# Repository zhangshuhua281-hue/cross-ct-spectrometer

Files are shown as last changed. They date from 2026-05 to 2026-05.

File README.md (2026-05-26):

# Cross C-T Spectrometer Prototype

交叉式 C-T 光谱仪原型设计。这个仓库整理了一个低成本光谱仪原型的光学设计、结构件、PCB、嵌入式固件、BOM 和实测数据处理结果，目标是方便复现、验证和继续改进。

本项目是实验原型，不是成熟仪器。当前资料适合学习、二次开发和原型复现；若用于定量测量，需要继续完成波长标定、白参考/暗参考流程、重复性验证和误差评估。

## What is included

- `hardware/optics/zemax`: Zemax 光学设计文件。
- `hardware/pcb`: TCD1304 驱动板、STM32G431 图像数据处理板的原理图和 PCB 工程压缩包。
- `hardware/mechanical/step`: 光谱仪外壳、镜架、隔离板、测试模块等 STEP 结构件。
- `firmware/stm32g431-image-control`: STM32G431 数据处理与显示链路固件，Keil MDK 工程。
- `firmware/esp32s3-monitor`: ESP32-S3 触摸屏监视器 Arduino 工程。
- `firmware/stm32f103-tcd1304-recovered`: STM32F103/TCD1304 采集固件的恢复版源码和串口协议说明。
- `data`: V1.0/V2.0/V3.0 原始采集数据、405 nm/780 nm 标定数据、处理后的 CSV/图像和分析脚本。
- `bom`: 镜片材料采购清单。
- `docs/project-report/project-report.pdf`: 项目报告 PDF。

## Repository layout

```text
.
├── bom/
├── data/
│   ├── raw/
│   ├── calibration/
│   ├── processed/
│   ├── validation/
│   └── legacy/
├── docs/
├── firmware/
├── hardware/
├── requirements-analysis.txt
└── README.md
```

## Quick start

1. 查看总体方案：打开 `docs/project-report/project-report.pdf`。
2. 查看硬件：先看 `hardware/pcb/schematics` 中的原理图，再看 `hardware/mechanical/step` 中的结构件。
3. 查看固件：STM32G431 工程入口是 `firmware/stm32g431-image-control/MDK-ARM/image-control.uvprojx`，ESP32-S3 工程入口是 `firmware/esp32s3-monitor/11_stm32_monitor.ino`。
4. 查看数据：优先看 `data/processed/v3.0/README.md`、`data/processed/v3.0/reports/processing_report.md` 和 `data/processed/v3.0/final_comparison`。
5. 重新跑 Python 数据处理脚本时，安装依赖：

```bash
pip install -r requirements-analysis.txt
```

## Default embedded chain

- 采集端：STM32F103/TCD1304 通过 `USART2` (`PA2/PA3`, `921600 8N1`) 向 STM32G431 提供 3648 点 12 位原始帧。
- 处理端：STM32G431 完成暗电平估计、中值滤波、Savitzky-Golay 平滑、归一化和下采样。
- 显示端：STM32G431 通过 `USART3` (`PB10/PB11`, `115200 8N1`) 向 ESP32-S3 输出文本包。
- 握手线：G431 `PA5(DATA_RDY)` 提示有待发送包，ESP32 `GPIO21(WAKE)` 拉高后 G431 才发送该包。

## Firmware build notes

- `firmware/esp32s3-monitor` 现在已经包含本地 `bsp_cst816.h/.cpp`，克隆仓库后不再缺少触摸驱动头文件。
- ESP32-S3 工程仍依赖 Arduino 环境中的 `lvgl` 与 `Arduino_GFX_Library`。
- `hardware/pcb/eda-archives` 保存当前公开版本的 PCB 工程压缩包，压缩包内部文件名可能与仓库文件名不同。

## Current status

- 已整理光学、结构、PCB、固件和测量数据。
- 已包含 TCD1304 采集链路、STM32G431 处理链路和 ESP32-S3 显示链路。
- V3.0 数据包含 12 组色卡、每组 5 次重复采集，以及 405 nm/780 nm 波长锚点数据。
- 当前仍需要继续完善定量标定、上位机源码、自动化构建和硬件复现文档。

## License

除文件内另有声明外，本仓库原创代码、文档、硬件设计资料和整理后的数据以 MIT License 发布。第三方文件保留其原始许可证声明，尤其是 STM32 HAL/CMSIS 相关文件。详见 `LICENSE` 和 `NOTICE.md`。

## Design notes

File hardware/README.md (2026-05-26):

# Hardware

硬件资料按光学、PCB 和结构件分开整理。

- `optics/zemax`: Zemax 光学设计文件。
- `pcb/schematics`: 两块电路板的 PDF 原理图。
- `pcb/eda-archives/G431图像数据处理板.zip`: STM32G431 图像数据处理板工程压缩包。
- `pcb/eda-archives/TCD1304驱动板.zip`: TCD1304 驱动板工程压缩包。
- `mechanical/step`: 3D 打印和结构装配用 STEP 文件。

当前 `pcb/eda-archives` 目录中的压缩包外层文件名已经按板卡用途整理；使用时建议与 `pcb/schematics` 中同名原理图 PDF 对照确认。

这些文件对应原型设计阶段资料，开板或加工前建议重新检查尺寸、公差、接口、连接器朝向和器件封装。

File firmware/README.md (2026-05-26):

# Firmware

## STM32G431 image-control

路径：`stm32g431-image-control`

用途：从 STM32F103/TCD1304 采集板读取 3648 点 12 位数据，完成暗电平估计、中值滤波、Savitzky-Golay 平滑、归一化和下采样，并通过串口输出给 ESP32-S3 显示端。

默认链路：

- STM32F103/TCD1304 -> STM32G431 `USART2` (`PA2/PA3`, `921600 8N1`)
- STM32G431 -> ESP32-S3 `USART3` (`PB10/PB11`, `115200 8N1`)
- 握手线：G431 `PA5(DATA_RDY)` -> ESP32 `GPIO18`，ESP32 `GPIO21(WAKE)` -> G431 `PA0`

工程入口：

- Keil MDK: `stm32g431-image-control/MDK-ARM/image-control.uvprojx`
- 应用逻辑：`stm32g431-image-control/App`
- 串口/板级驱动：`stm32g431-image-control/BSP`

## ESP32-S3 monitor

路径：`esp32s3-monitor`

用途：触摸屏监视器，接收 STM32G431 串口输出并显示曲线、分组统计和链路状态。

工程入口：

- Arduino sketch: `esp32s3-monitor/11_stm32_monitor.ino`

构建说明：

- 目录内已包含本地触摸驱动 `bsp_cst816.h/.cpp`，不再依赖仓库外的同名头文件。
- 仍需在 Arduino/PlatformIO 环境中安装 `lvgl` 和 `Arduino_GFX_Library`。

## STM32F103 TCD1304 recovered firmware

路径：`stm32f103-tcd1304-recovered`

用途：记录从实物 Flash 反汇编整理出来的 TCD1304 采集固件逻辑、串口命令和积分时间表。

注意：这是恢复版源码，适合理解和移植，不保证直接编译得到与实物导出固件逐字节一致的 HEX。

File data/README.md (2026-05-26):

# Measurement Data

测量数据按原始数据、标定数据、处理结果和旧版分析结果分开。

## Raw data

- `raw/v1.0-cards`: V1.0 色卡与镜片参考采集数据。
- `raw/v2.0-cards`: V2.0 色卡采集数据。
- `raw/v3.0-cards`: V3.0 色卡采集数据，共 12 组，每组 5 次重复。

原始 TXT 通常包含 `Pixel, ADC, VoltageV` 三列。数据处理时默认跳过前 20 行瞬态/平台点，并使用前 16 点估计暗电平。

## Calibration data

- `calibration/405nm`: 405 nm 光源锚点数据。
- `calibration/780nm`: 780 nm 光源锚点数据。

## Processed data

- `processed/v1.0`: V1.0 数据处理脚本、CSV、报告和图像。
- `processed/v3.0`: V3.0 数据处理脚本、CSV、报告、最终对比和 405/780 nm 线性标定结果。

优先查看：

- `processed/v3.0/reports/processing_report.md`
- `processed/v3.0/final_comparison`
- `processed/v3.0/wavelength_calibration_405_780`

## Legacy and validation

- `legacy/origin-smooth-selected-skip20`: 早期平滑与差异分析结果。
- `validation/tcd1304-validity`: TCD1304 有效性和组间相关性分析结果。

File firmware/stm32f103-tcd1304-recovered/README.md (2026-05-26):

# STM32F103C8T6 采集固件恢复源码说明

这个目录是根据当前实物单片机 Flash 导出的 `tcd1304_mcu_flash_64k.bin/.hex` 反汇编后整理的源码包。

它不是原作者的原始工程源码。HEX/BIN 里没有变量名、注释、C 文件结构和 Keil 工程分组信息，所以这里整理的是“等价逻辑恢复版”，用于理解、继续移植和后续修改。

## 文件

- `src/tcd1304_firmware_recovered.c`
  - 采集固件主逻辑恢复版。
  - 包含串口命令处理、积分时间表、12 位/8 位数据发送、摘要帧发送、DMA 完成中断逻辑。
- `docs/protocol.md`
  - 上位机与单片机串口协议。
- `docs/recovery_notes.md`
  - 恢复依据、已确认硬件、未完全还原部分。

## 已确认功能

- 串口：USART1，`921600 8N1`
- 采集命令：
  - `0xA1`：发送 3648 点 12 位数据，低字节在前，共 7296 字节。
  - `0xA2`：发送 3648 点 8 位数据，共 3648 字节。
  - `0xA3`：发送摘要帧，帧头 `0xFE`，共 12 字节。
- 积分时间命令：
  - `0xB1` 到 `0xD8`
  - 对应 `10 us` 到 `3 s`

## 重要边界

当前目录里的源码适合继续开发和移植，但不能保证直接编译后得到和实物导出固件逐字节相同的 HEX。

如果要在源码层继续改单片机逻辑，建议以 `src/tcd1304_firmware_recovered.c` 为依据，把 `board_*` 底层函数移植到 Keil 标准外设库工程中，然后用示波器确认 TCD1304 的 MCLK、SH、ICG 等时序。

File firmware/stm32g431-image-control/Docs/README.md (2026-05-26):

# image-control

STM32G431RBTx HAL base project for Keil5.

## Directory layout

- `App`: application logic, processing pipeline, group statistics
- `BSP`: board-level drivers and pin abstraction
- `Core`: startup, interrupt handlers, clock config, HAL MSP
- `Drivers`: local CMSIS and HAL drivers copied from STM32CubeG4
- `MDK-ARM`: Keil5 project files
- `Docs`: project notes

## Current baseline

- Device target: `STM32G431RBTx`
- Framework: `STM32CubeG4 HAL`
- Clock: HSI -> PLL -> 170 MHz
- Input UART: `USART2`, `PA2(TX)` / `PA3(RX)` linked to the STM32F103 TCD1304 capture board
- Display link UART: `USART3`, `PB10(TX)` / `PB11(RX)` to ESP32-S3 upper display
- `PA2` is reserved for `USART2_TX` in the default acquisition chain and must not be reused as a debug GPIO
- Handshake GPIO:
  - `PA5`: `DATA_RDY` output to ESP32 `GPIO18`
  - `PA0`: `WAKE` input from ESP32 `GPIO21`
- Processing scope for current firmware:
  - dark level estimation from the first 16 ADC points using median
  - skip the first 20 points
  - `Intensity = dark_adc - ADC`
  - 9-point median filter
  - 151-point 3rd-order Savitzky-Golay smoothing
  - clamp smoothed output to `>= 0`
  - max normalization on the smoothed curve
  - lightweight per-group accumulation and QC summary
- Not included yet:
  - white-reference normalization
  - area normalization
  - wavelength calibration
  - PC-side plots and reports
  - full-resolution multi-replicate history retention

## Embedded mapping to the PC workflow

- The G431 firmware keeps the main per-frame processing chain from `scripts/process_v3_tcd1304.py`.
- To stay within MCU RAM limits, it does not keep every full-resolution curve for every group.
- The firmware processes one frame at a time, then keeps only:
  - frame summary values
  - a downsampled normalized curve for current group QC accumulation
  - lightweight group-level statistics

## Serial protocol assumptions

- Input source on `USART2` is the recovered STM32F103 capture firmware.
- G431 requests one frame by sending command `0xA1`.
- F103 replies with one full 12-bit frame:
  - `3648` pixels
  - `2` bytes per pixel
  - little-endian (`low byte` then `high byte`)
  - total payload `7296` bytes
- Pixel axis used by the G431 pipeline:
  - first pixel index is treated as `0`
  - first `20` pixels are skipped by the processing chain
- Current group mapping in this firmware:
  - every pulled F103 frame is tagged as `group 1`
  - `replicate_id` is auto-incremented locally on G431 for QC accumulation
- ESP32 output content on `USART3`:
  - `PKT BEGIN SEQ=<n>`
  - `FRAME ...`
  - `GROUP ...`
  - `CURVE_BEGIN ...`
  - repeated `CURVE <pixel> <q15>`
  - `CURVE_END`
  - `PKT END`
- Handshake behavior:
  - every completed frame is converted into one display packet
  - `DATA_RDY` stays high while a packet is pending
  - if `WAKE` is low, the latest packet is held until ESP32 is ready
  - if `WAKE` is high, the packet is sent immediately
  - only one packet buffer is kept on the G431 side, so acquisition pauses until the pending packet is drained

## Next recommended changes

- Add DMA or interrupt-based UART receive on `USART2` if the F103 frame rate becomes too high for polling.
- Replace the temporary fixed `group 1` tag with a real group/replicate source if the upstream board can provide metadata.
- Keep wavelength calibration as a later stage after your new calibration data is ready.

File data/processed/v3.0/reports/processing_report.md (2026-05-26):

# V3.0 TCD1304 数据处理报告

## 数据理解

- 原始目录：`data/raw/v3.0-cards`
- 文件数：60；色卡组数：12；每组 5 次重复采集。
- 每个原始文件包含 `Pixel, ADC, VoltageV` 三列，实际像素点数为 3647。
- 前 20 行视为读出瞬态或起始平台，保留用于检查，但不纳入有效曲线。

## 处理流程

1. 按文件名 `A-B.txt` 解析 `A` 为色卡编号，`B` 为重复序号。
2. 取前 16 个高平台点的中位数作为 `dark_adc`。
3. 计算 `IntensityADC = dark_adc - ADC`。
4. 对有效曲线做 9 点中值滤波和 151 点三阶 Savitzky-Golay 平滑。
5. 每组 5 次测量求均值，输出组内重复性、组间相关矩阵和最终对比图。

## 主要结论

- 60 条样本可以按文件名稳定解析为 12 组，并完成组内重复性和组间相关矩阵汇总。
- 从组均值曲线和组间相关矩阵看，V3.0 数据的组间差异明显优于早期数据。
- 组内平均相关系数整体较高，说明重复采集的一致性较好。
- 第 12 组峰值位置明显偏后，需要结合采集条件确认它是有效样品差异还是采集异常。
- 当前波长标定只使用 405 nm 和 780 nm 两个锚点，属于线性初步标定，不能替代完整标定流程。

## 重点输出

- `data/04_quality_control/group_repeatability_stats.csv`
- `data/04_quality_control/between_group_correlation.csv`
- `data/02_group_means/all_group_means_smoothed_normalized_wide.csv`
- `final_comparison/V3.0_色卡最终对比图_平滑归一化.svg`
- `wavelength_calibration_405_780/405_780_线性波长标定公式.csv`

## QC 摘要

| 组别 | 重复数 | 组内平均相关 | 平均点位 CV | 平均峰值像素 |
|---:|---:|---:|---:|---:|
| 1 | 5 | 0.999896 | 0.002819 | 2343.8 |
| 2 | 5 | 0.999949 | 0.003127 | 2339.8 |
| 3 | 5 | 0.999917 | 0.001547 | 2339.4 |
| 4 | 5 | 0.999916 | 0.003826 | 2342.0 |
| 5 | 5 | 0.999877 | 0.002402 | 2340.2 |
| 6 | 5 | 0.999923 | 0.004357 | 2340.0 |
| 7 | 5 | 0.999940 | 0.001955 | 2337.0 |
| 8 | 5 | 0.999806 | 0.002343 | 2076.8 |
| 9 | 5 | 0.999936 | 0.003482 | 2338.6 |
| 10 | 5 | 0.999941 | 0.001884 | 2340.0 |
| 11 | 5 | 0.999955 | 0.003770 | 2340.4 |
| 12 | 5 | 0.999946 | 0.001186 | 3450.4 |

未发现完全重复文件。

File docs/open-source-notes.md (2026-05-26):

# Open Source Notes

整理时保留了能帮助复现和验证的资料，排除了更适合发布到 GitHub Releases 或不适合公开再分发的文件。

## Kept

- 光学设计文件、PCB 原理图和 PCB 工程压缩包。
- 结构 STEP 文件。
- STM32G431、ESP32-S3 和 STM32F103 恢复版固件资料。
- V1.0/V2.0/V3.0 原始采集数据。
- V1.0/V3.0 处理后的 CSV、SVG、PNG 和脚本。
- 项目报告 PDF。

## Excluded

- 编译输出和本地工程临时文件。
- 预编译 Windows 上位机 EXE。
- MATLAB `.fig` 二进制图。
- 参赛视频、PPT、DOCX。
- 参考文献 PDF。

## Before publishing

发布到 GitHub 前建议人工检查一次 `docs/project-report/project-report.pdf`，确认其中没有不想公开的姓名、学校、联系方式、比赛账号或未授权图片。

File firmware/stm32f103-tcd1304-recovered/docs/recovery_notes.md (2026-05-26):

# 固件恢复说明

## 来源

恢复依据是当前实物 STM32F103C8T6 读出的完整 Flash：

- `tcd1304_mcu_flash_64k.bin`
- `tcd1304_mcu_flash_64k.hex`

反汇编与分析文件包括中断向量、函数反汇编和恢复版伪代码。当前开源仓库只保留整理后的恢复版源码和说明。

## 与旧工程的关系

旧 Keil 工程的 `OBJ/USART.hex` 和当前实物单片机里的固件不同。

从旧工程源码看，它更像是通过 USART2 向另一个采集模块请求数据的程序；而实物固件本身使用 ADC1、DMA1 Channel1、TIM2/TIM3/TIM4/TIM1 和 USART1，直接完成 TCD1304 采集和数据返回。

所以本目录没有直接覆盖旧工程，而是单独整理恢复版源码，避免把两个不同固件混在一起。

## 已确认硬件/外设

| 项目 | 恢复结果 |
|---|---|
| MCU | STM32F103C8T6，Flash 64KB |
| 串口 | USART1，921600 8N1 |
| ADC | ADC1 |
| DMA | DMA1 Channel1 |
| 定时器 | TIM1、TIM2、TIM3、TIM4 均有使用 |
| 中断 | USART1、DMA1 Channel1、TIM2 |
| ADC DMA 源地址 | `0x4001244C`，即 ADC1 数据寄存器 |
| DMA 目标缓冲 | RAM `0x20000064` |
| 发送工作缓冲 | RAM `0x20001D40` |
| 原始 DMA 点数 | `0xE6E`，即 3694 点 |
| 实际发送像素 | 3648 点 |
| 发送起始偏移 | 跳过原始缓冲前 32 点 |

## 未完全还原的部分

这些内容在 HEX 里可以看到寄存器行为，但没有原始语义名，需要用示波器或实物电路继续确认：

- PA8、PA0、PB0、PB9 分别对应 TCD1304 的哪个具体时序脚。
- TIM1/TIM2/TIM3/TIM4 之间的触发关系。
- `timing_a`、`timing_b`、`timing_c` 三个参数在原始源码中的变量名。
- 长积分时间下，传感器暗电流、饱和、时钟稳定性对采集结果的影响。

## 后续改源码的建议

如果要继续修改积分时间，优先改 `src/tcd1304_firmware_recovered.c` 里的 `kIntegrationPresets` 表。

如果要把恢复版变成可重新编译的 Keil 工程，建议步骤是：

1. 复制旧 Keil 工程为新目录，不要覆盖原目录。
2. 把 `src/tcd1304_firmware_recovered.c` 拆成 `main.c`、`tcd1304.c`、`tcd1304.h`。
3. 在工程中加入 `stm32f10x_adc.c`、`stm32f10x_dma.c`、`stm32f10x_tim.c`。
4. 用 STM32 标准外设库实现源码中的 `board_*` 底层函数。
5. 编译后先在示波器上确认 TCD1304 时序，再接上位机采集。

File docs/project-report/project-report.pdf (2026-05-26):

附件 6

# 创意组

# 创意策划书

## 竞赛题目： 交叉式 C-T 光谱仪原型设计

竞赛队名： | 分光捉影

指导教师推荐理由：（希望评委关注的亮点，言简意赅、切忌浮夸、否则会影响成绩、80

字内）

1、利用交叉 C-T 光路，光谱仪集成度高，可实现轻量化微型化

2、光谱仪动态范围广，采集数据稳定可靠

3、系统采用模块化设计，具备多领域应用拓展能力
4、
5、 | 织委员会制

### 二〇二六年四月

序号

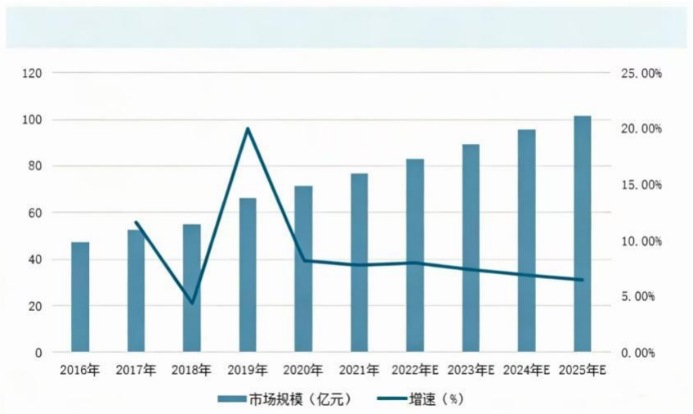
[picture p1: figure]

创

意

策

划

方

案

## 一、产品背景以及市场分析

通过对目前微型光谱仪和光纤光谱仪系统的分析可得。光谱信息能够反映被测 物体对不同波长光的吸收、反射或透射特性，因此可用于材料识别、颜色分析、环 境检测、物质成分判断等场景。
行业报告显示，中国光谱仪产量从 2019 年的 2.14 万台增长至 2023 年的 3.85 万台，同期需求量为 4.01 万台，显示出稳定的市场供需关系。且全球光谱仪市场 持续增长，市场规模从 2016 年的 47.2 亿元增长至 2024 年的 102.1 亿元。这些数据

表明，光谱仪市场，特别是中国市场和特定技术领域，拥有坚实增长基本盘。 二、国内外技术分析

目前，国内外光谱仪技术已经较为成熟，国外代表性产品具有检测精度高、稳 定性好、软件系统完善等特点，但价格普遍较高，在中低端市场存在明显价格壁垒。 国内光谱仪技术近年来发展较快，但微型光谱仪刚起步，集成度高但波长范围窄、 分辨率受限，往往难以获得理想的检测效果。
因此，设计一种精度高、价格低廉的微型光谱仪具有一定意义。本项目以此为 定位，采用交叉式 C-T 光路并配合自研采集系统，提升反射光谱采集的稳定性和颜

色差异分析能力。 三、技术方案论证

光谱仪是一种光学精密仪器，它的核心功能是将待测光信号按照不同波长进行 空间分离，并通过探测器采集不同波长处的光强信息，最终得到物体或样品的光谱 曲线，由狭缝、准直镜、色散元件、聚焦镜、成像系统等部分组成。本方案在此基 础之上给予创新，由三大模块构成：第一部分为前置照明与反射测量光路，第二部 分为光谱分光与成像系统，第三部分为信号采集、处理与显示系统。 设计过程先根据分辨率、狭缝宽度、光栅线数和 CCD 有效长度计算初始参数，

图 1.2016—2025 年中国光谱仪市场规模及预测情况

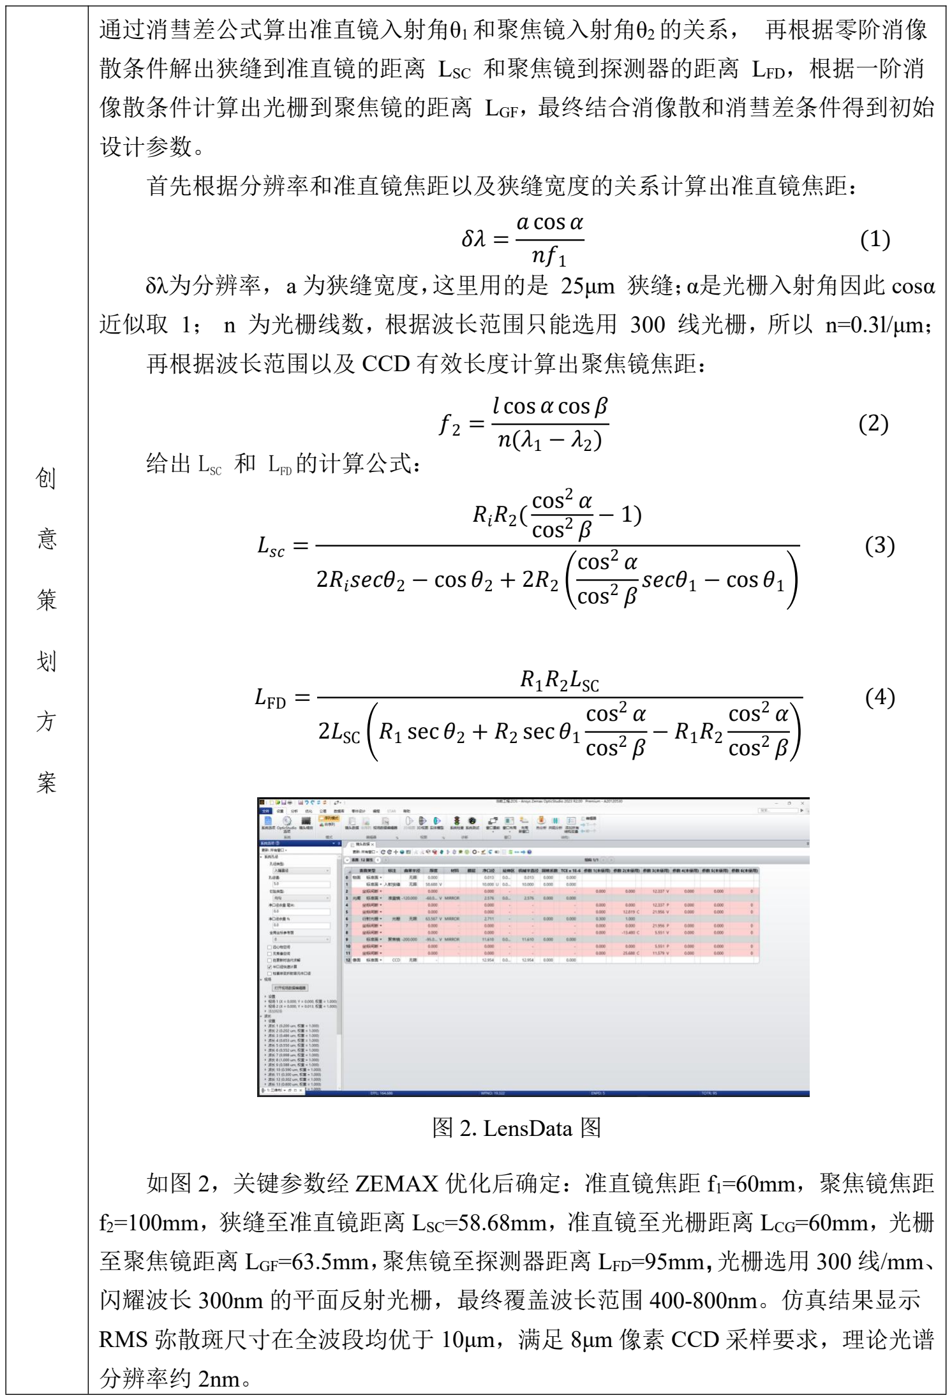
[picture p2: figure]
通过消彗差公式算出准直镜入射角θ1和聚焦镜入射角θ2的关系， 再根据零阶消像; 散条件解出狭缝到准直镜的距离 LSC 和聚焦镜到探测器的距离 LFD，根据一阶消; 像散条件计算出光栅到聚焦镜的距离 LGF，最终结合消像散和消彗差条件得到初始; 设计参数。; 首先根据分辨率和准直镜焦距以及狭缝宽度的关系计算出准直镜焦距：; δλ为分辨率，a 为狭缝宽度，这里用的是 25μm 狭缝；α是光栅入射角因此 cosα; 再根据波长范围以及 CCD 有效长度计算出聚焦镜焦距：; 给出 LSC 和 LFD的计算公式：; 如图 2，关键参数经 ZEMAX 优化后确定：准直镜焦距 f1=60mm，聚焦镜焦距; 至聚焦镜距离 LGF=63.5mm，聚焦镜至探测器距离 LFD=95mm，光栅选用 300 线/mm、; 闪耀波长 300nm 的平面反射光栅，最终覆盖波长范围 400-800nm。仿真结果显示; 分辨率约 2nm。;  cos  1;  cos  cos  (1 − 2); 2( cos; cos; 2s2 − cos 2 + 22; s1 − cos 1; 12SC 2SC 1 sec 2 + 2 sec 1; 图 2.LensData 图

近似取 1； n 为光栅线数，根据波长范围只能选用 300 线光栅，所以 n=0.3l/μm；

## f2=100mm，狭缝至准直镜距离 LSC=58.68mm，准直镜至光栅距离 LCG=60mm，光栅

RMS 弥散斑尺寸在全波段均优于 10μm，满足 8μm 像素 CCD 采样要求，理论光谱

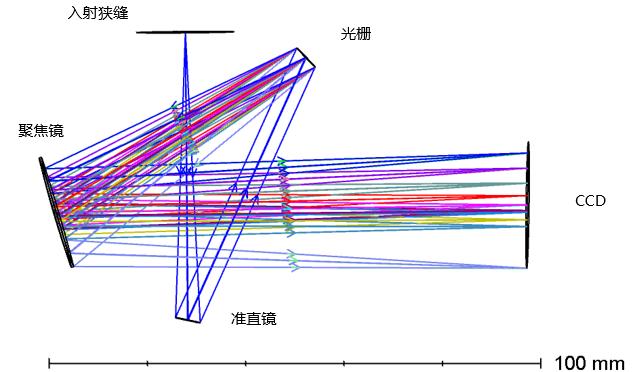
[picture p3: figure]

创

意

策

划

方

案

本方案采用交叉式 Czerny-Turner（C-T）结构，对比非交叉式 C-T 结构，空间 利用率更高，杂散光路径更短，整机尺寸可控制在 160×180×85mm 以内，满足 Shafer 彗差消除条件，同时引入零阶及一阶像散消除约束，通过 ZEMAX 光学仿真优化。

图 3 展示了优化后交叉式 C-T 结构光谱仪的光路设计结果，为进一步验证该结 构在全波段范围内的成像质量，下面结合图 4 所示的光路点列图，对不同波长下的

像点分布及弥散特性进行分析。

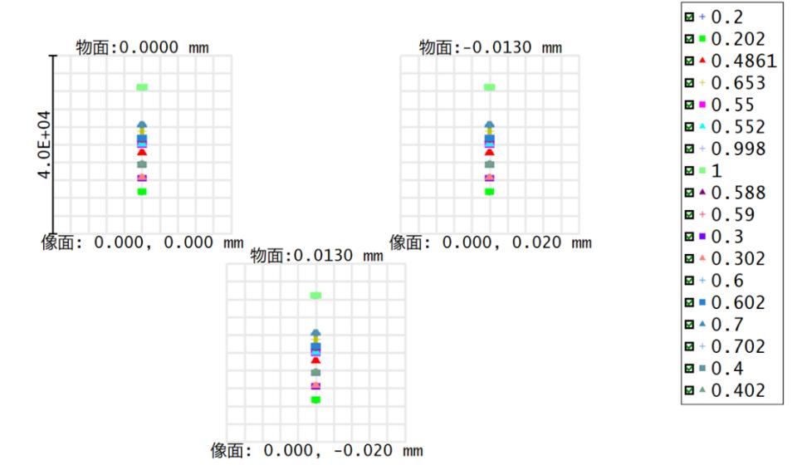
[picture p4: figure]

从图 5 可看出，优化后的结构在色散方向的像散显著降低，像点分布集中、弥

散范围较小；即使存在轻微像散，也应主要沿非色散方向分布，以减小对光谱分辨 率的影响。

图 3.光路结构示意图

图 4.光路点列图

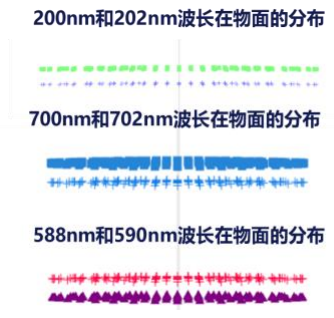
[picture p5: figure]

创

意

策

划

方

案

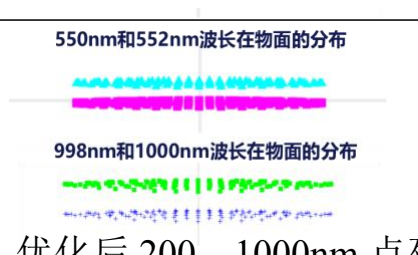
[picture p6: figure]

除光路设计与优化外，项目还自主完成了电子采集、参数配置和数据输出系统， 使样机具备可运行、可重复测试和可规范导出的工程能力。
项目围绕 TCD1304 线阵 CCD 自研驱动板，集成 3.3V 稳压、去耦滤波、8MHz 晶振、STM32F103C8T6 主控、CCD 接口和串口/下载接口。下位机输出 SH、ICG、 M 等关键时序，完成积分时间切换、采样数据打包和串口上传。相比通用开发板飞

线调试，自研板卡能够缩短信号链路，降低噪声耦合和接触不稳定问题，也便于后 续与光机外壳进行一体化安装。

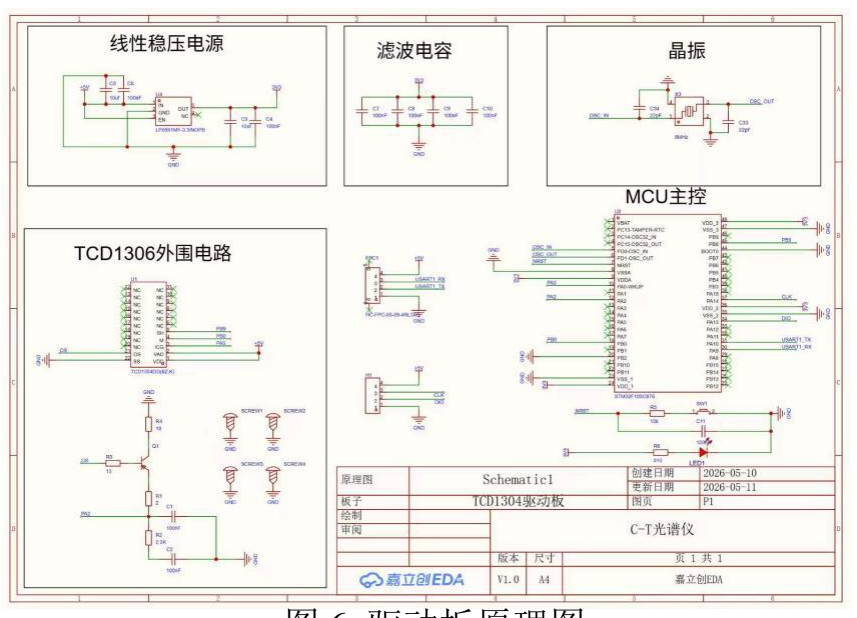
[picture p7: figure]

在原理图确定后，进一步完成了驱动板 PCB 布局布线与三维结构建模，如图 7 及图 8 所示。PCB 布局将主控、时钟、电源和 CCD 接口分区布置，缩短关键控制 线和模拟输出线。系统支持完整数据帧，积分时间可由 10μs 扩展至 3s，常规色卡 测试可在 1-200ms 范围内调节，从而兼顾弱信号可见性与强信号防饱和需求。

## 图 5.优化后 200—1000nm 点列图

图 6.驱动板原理图

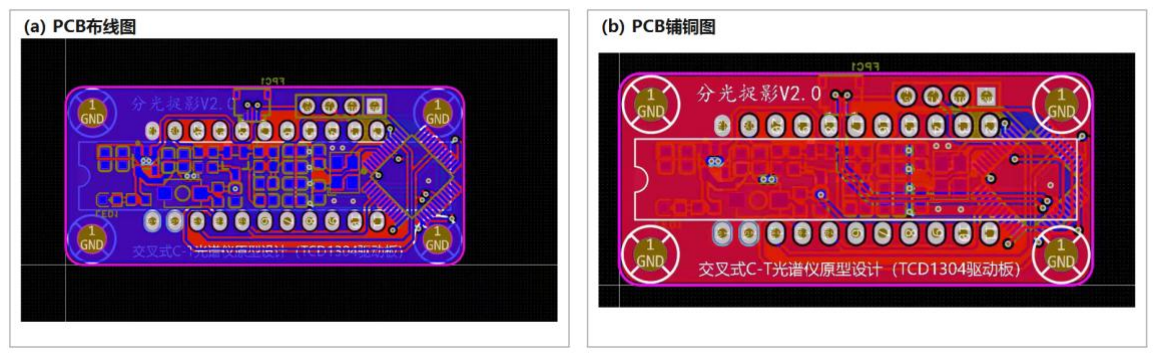
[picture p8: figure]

图 7.PCB 布线图及其铺铜图

创

意

策

划

方

案

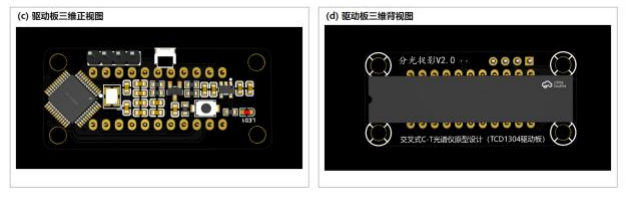
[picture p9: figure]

上位机采用 C# WinForms 开发，支持串口连接、实时曲线显示、手动/定时采 集、积分时间设置、单次导出和批量导出。导出数据统一包含 Pixel、ADC 和 VoltageV 三列，可直接进入 Python 或 MATLAB 处理流程，减少人工整理误差，并为暗电平

扣除、白纸校正、面积归一化和波长标定提供统一数据基础。 驱动板、STM32 固件与上位机共同构成完整采集链路：硬件提供稳定接口， 固件执行 CCD 时序和数据上传，软件完成显示、配置、导出和后续校正，为样机

实测、波长标定与颜色区分提供支撑。 四、技术路线设计及产品外观

整机工作流程：宽谱 LED 发光→准直透镜→半透半反分束镜（50:50）；透射

部分射向被测样品/参考白板，反射光返回后经分束镜二次反射；反射部分与样品 反射光在第二聚焦透镜处汇聚，共同耦合进入入射狭缝；光经狭缝进入 C-T 分光系 统完成色散和成像，线阵 CCD 采集光谱。

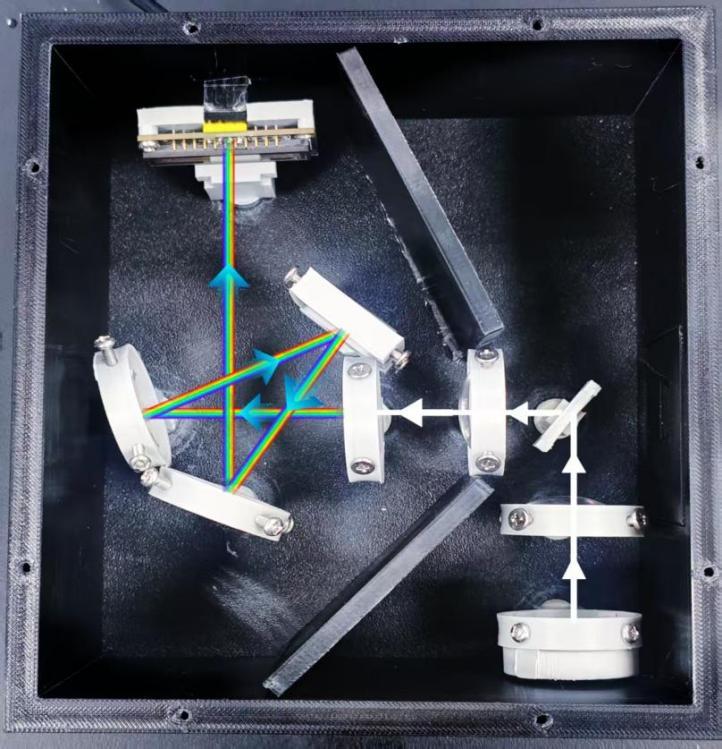
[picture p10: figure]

图 9.光谱仪实体图

图 8.驱动板三维图

创

意

策

划

方

案

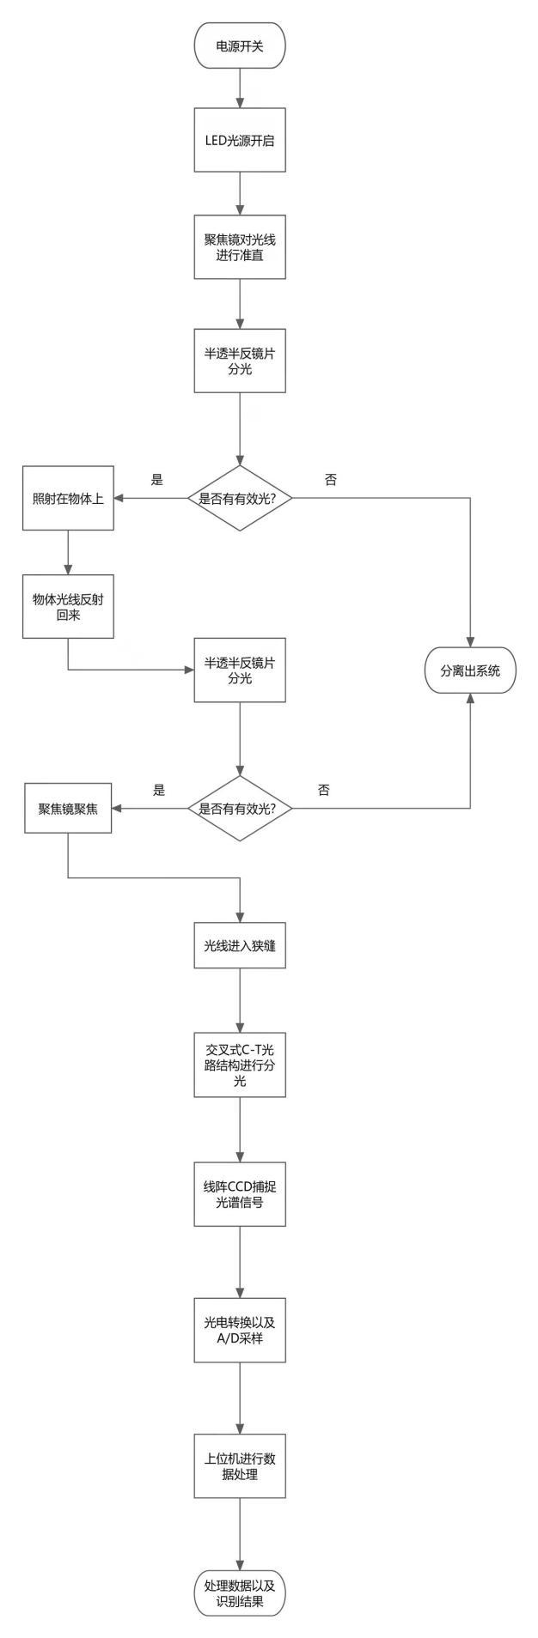
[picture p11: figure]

图 10.整机工作流程图

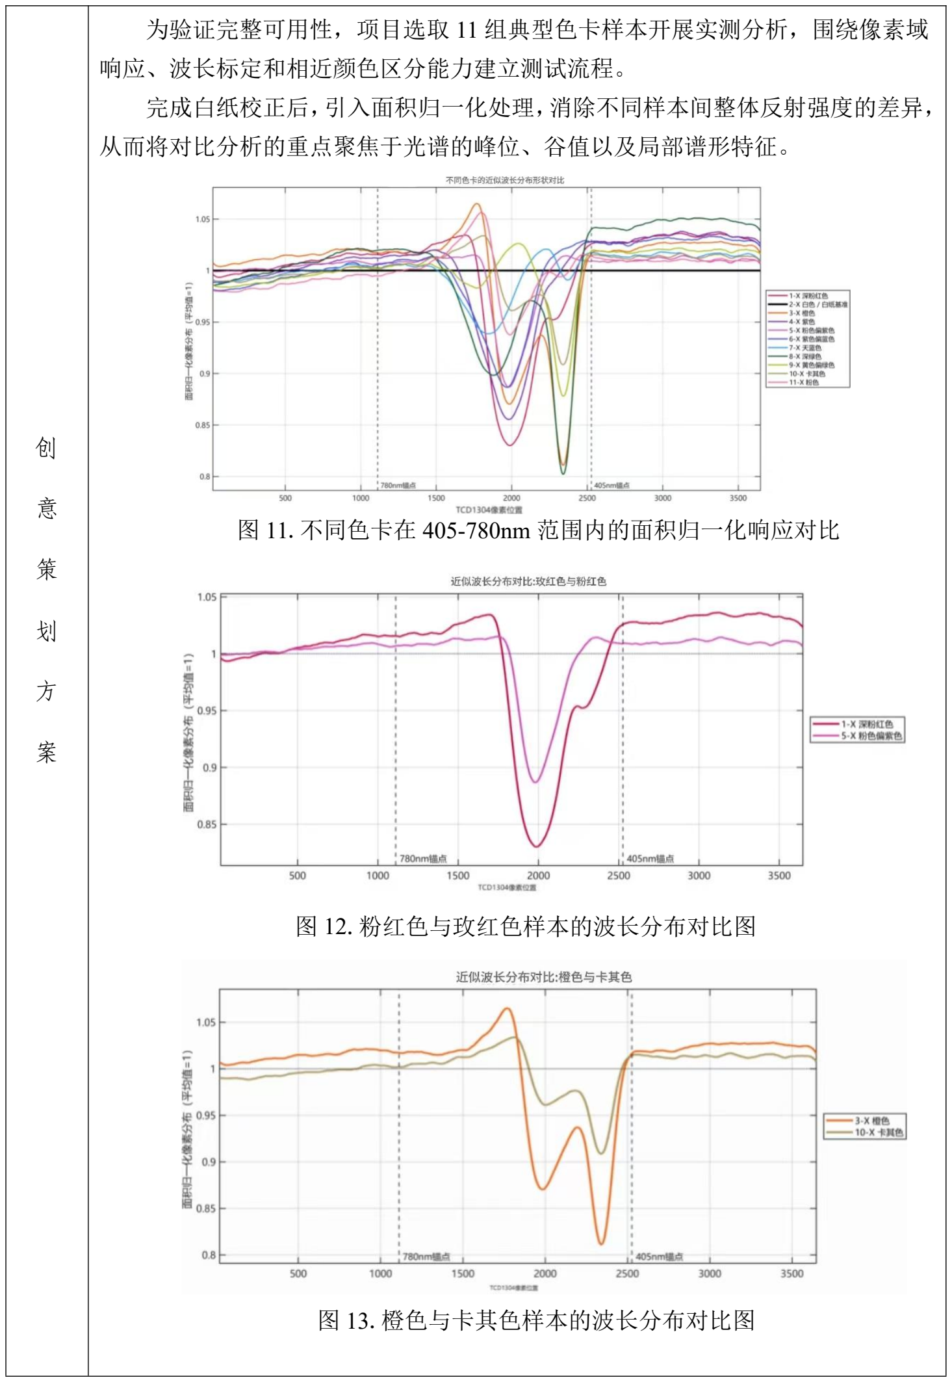
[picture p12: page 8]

创

意

策

划

方

案

为验证完整可用性，项目选取 11 组典型色卡样本开展实测分析，围绕像素域

响应、波长标定和相近颜色区分能力建立测试流程。
完成白纸校正后，引入面积归一化处理，消除不同样本间整体反射强度的差异， 从而将对比分析的重点聚焦于光谱的峰位、谷值以及局部谱形特征。

图 11.不同色卡在 405-780nm 范围内的面积归一化响应对比

图 12.粉红色与玫红色样本的波长分布对比图

图 13.橙色与卡其色样本的波长分布对比图

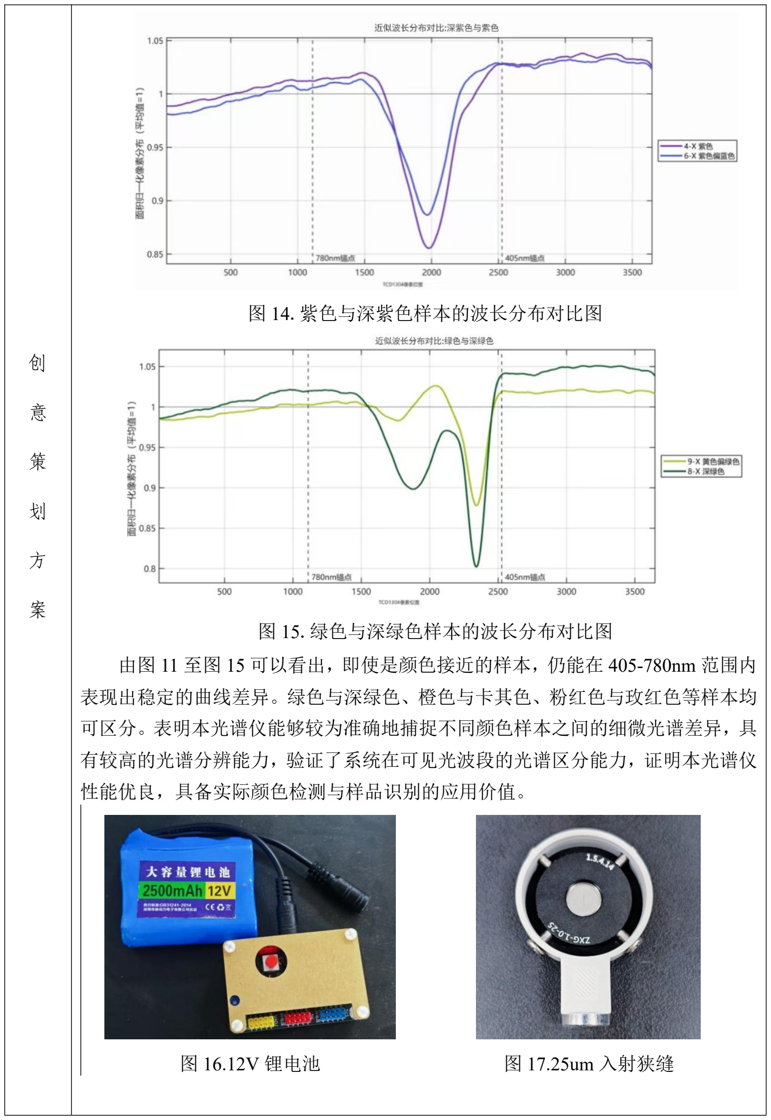
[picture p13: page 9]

创

意

策

划

方

案

由图 11 至图 15 可以看出，即使是颜色接近的样本，仍能在 405-780nm 范围内

表现出稳定的曲线差异。绿色与深绿色、橙色与卡其色、粉红色与玫红色等样本均 可区分。表明本光谱仪能够较为准确地捕捉不同颜色样本之间的细微光谱差异，具 有较高的光谱分辨能力，验证了系统在可见光波段的光谱区分能力，证明本光谱仪 性能优良，具备实际颜色检测与样品识别的应用价值。

图 16.12V 锂电池 | 图 17.25um 入射狭缝

图 14.紫色与深紫色样本的波长分布对比图

图 15.绿色与深绿色样本的波长分布对比图

图 18.300 线 300nm 闪耀波长 | 图 19.焦距 100mm 反射式聚焦镜

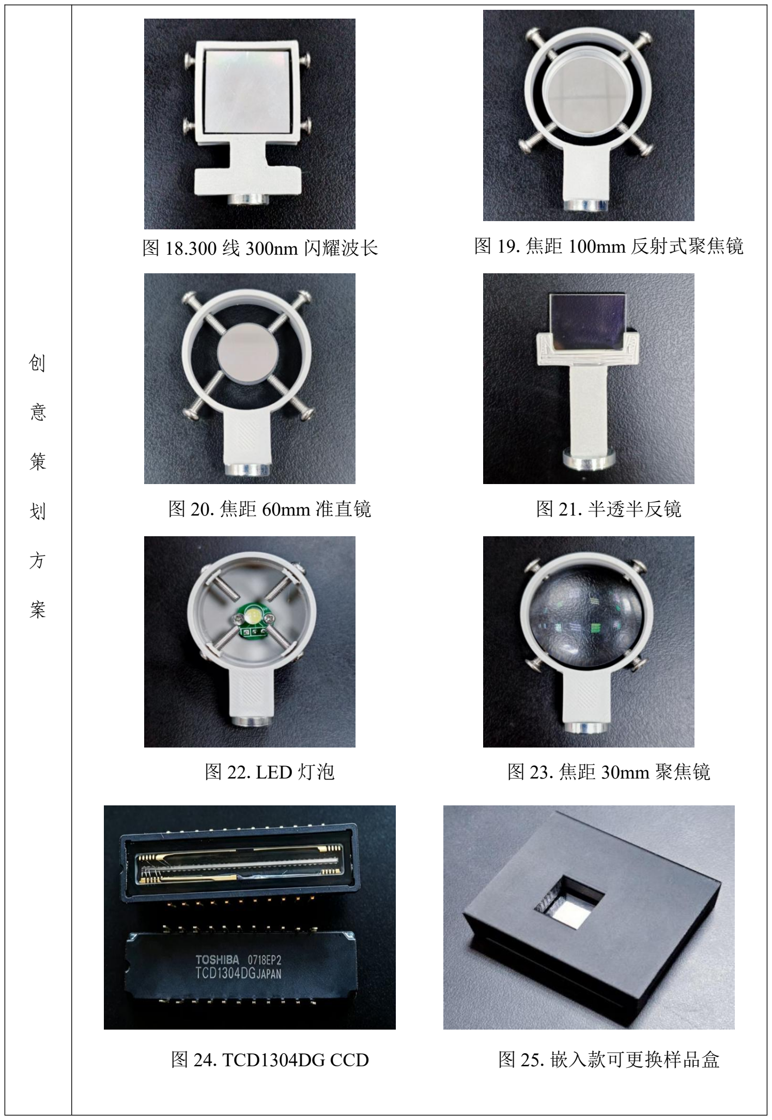
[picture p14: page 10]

创

意

策

划

方

案

图 20.焦距 60mm 准直镜 | 图 21.半透半反镜
图 22.LED 灯泡 | 图 23.焦距 30mm 聚焦镜
图 24.TCD1304DG CCD | 图 25.嵌入款可更换样品盒

创

意

策

划

方

案

## 入射狭缝：狭缝宽度 25±5um，长度 3mm,材料为 302Stainless Steel，直径

25.4mm。
衍射光栅：平面衍射光栅尺寸 25×25mm，厚度为 6mm，刻线为 300L/mm，闪

## 耀波长为 300nm，衍射波段为：200-850nm。

反射式聚焦镜：尺寸直径为 25mm，焦距为 100mm，边厚为 6.39mm，厚度为 6mm，镀膜为紫外铝膜，材料为精退火 H-K9L 光学玻璃。

准直镜：尺寸直径 17mm，焦距 60mm，曲率半径为 120mm，中心厚度为 3.7mm， 边缘厚度为 4.75mm，凹面镀膜为紫外增强铝膜。

## 半透半反镜：尺寸为 14×17×1.1mm，波长指标为 400-700nm，镀膜为 IAD 多

层介质硬膜。

聚焦镜×2：透射式聚焦镜，直径 30mm，焦距 30mm。

## TCD1304DG：东芝 TCD1304，像素大小为 8um×200um，像素共计 3684，波 长响应范围为 300nm—1000nm。

嵌入款可更换样品盒：外部结构尺寸为 50×60×17mm，内设小孔 15×15×7mm，

可更换光谱仪需要测试的样品。 五、创新性

本系统在结构设计、检测性能和应用拓展方面具有较强的创新性，主要体现在 以下三个方面。
系统具有显著的微型化与集成化优势。装置采用交叉式 Czerny-Turner 光路结 构，将光源、分光、探测及信号处理等核心光学元件高度集成于 PETG 外壳内部， 整机尺寸约为 160×180×85mm，在保证光谱检测功能完整性的同时，实现了设备

的小型化、轻量化与便携化。
团队自研 TCD1304 驱动板、STM32 采集固件和 C#上位机程序，实现 CCD 时

序驱动、积分时间调节、实时显示、批量采集和标准化导出。该链路使系统不仅能 够采集数据，而且能够稳定重复测试、规范保存数据并持续优化，增强了自主技术 含量和工程完整性。
系统具备高精度、快速响应的光谱检测能力。系统采用线阵 CCD 探测器进行

全波段同步采集，兼顾检测效率与信号质量。与此同时，系统支持自动曝光控制， 可依据样品反射率强弱自动优化积分时间，从而提升动态范围和测量稳定性。 系统具有良好的适用性与应用扩展能力。一方面，本系统可对不同颜色、不同 材质样品的反射光谱进行采集与分析。另一方面，系统具备较强的模块化扩展潜力： 可将检测范围进一步拓展至近紫外或近红外波段，从而应用于荧光检测、植被分析、 食品品质检测等更多领域。

创

意

策

划

方

案

| 综上，本系统以微型化设计、高精度检测及模块化拓展为核心创新点，具备显 著的自主化水平与实际应用前景。 六、产品成本及市场估值
产品零件 | 型号/规格 | 数量 | 单价
CCD | TCD1304DG | 1 | 100
入射狭缝 | 缝宽 25um | 1 | 145
衍射光栅 | 25×25×6mm,刻线 300,闪耀波长 300nm | 1 | 320
镀银凹面准直镜 | 焦距 60mm | 1 | 95
紫外铝凹面聚焦镜 | 焦距 100mm | 1 | 240
半透半反镜 | 14×17×1.1mm | 1 | 13
聚焦镜 | 直径 30mm | 2 | 60
反射镜 | 25×25mm | 1 | 2
LED 灯 | 5V | 1 | 5
锂电池 | 3S，12V | 1 | 12
合计 | —— | —— | 992
1.市场现状

光谱检测广泛应用于食品安全、工业在线质检、医疗辅助诊断等多个领域。随 着智能制造、食品监管和科学仪器国产化需求增长，国内光谱仪市场呈现出稳定上 升态势。根据市场研究数据，全球光谱仪市场规模 2024 年已超过 100 亿元，预计 到 2028 年将突破 280 亿元，年均增速约 7%。具备高度集成、低成本特点的微型光

谱仪在国内市场具有巨大的发展潜力。
2.产品种类和价格

企业版：适用于纺织、印刷、涂料等工业质检用户及高校科研实验室，针对客 户需求进行定制化开发，提供更高精度和专属技术支持服务，定价 20000-30000 元。

民用版：适用于个体用户、中学创新实验室，满足用户对便携式光谱检测及教

## 学演示的需求，定价 12000-15000 元。 七、团队介绍

团队具备光学设计、机械建模、嵌入式开发和市场分析能力能够完成从方案设 计到样机搭建、测试和推广的闭环。
团队成员一：负责光学设计、ZEMAX 仿真、SolidWorks 结构建模、STM32 驱 动、CCD 时序和 ADC 采集。完成了光谱仪光路系统的整体设计，在 ZEMAX 中建 立了交叉式 Czerny-Turner 光路模型，最终通过公差分析给出了镜片加工与装配的

公差范围，生成了可投入制作的光学设计文件。
团队成员二：负责机械结构搭建、样机装调、数据处理和颜色识别算法，并完

创

意

策

划

方

案

成外壳加工图纸与系统装配。绘制了外壳 3D 打印图纸，完成了样机装调，装配出

可工作的微型光谱仪。
团队成员三：主要负责项目财务管控与市场调研，推动微型光谱仪的商业化落 地。完成了核心元器件的供应链询价与 BOM 成本核算。搭建了销售预测模型，主

导了产品外形的概念设计、高精度渲染及宣发物料制作，构建了完整的产品商业体 系。
团队成员均具备一定的工程实践能力。成员分工明确，相互协作完成系统联调 与测试，保证各模块接口兼容、整机功能完整。 八、产品营销计划

1.定位市场：

本产品目标市场分三类：第一类为教研市场，高校光学/光电类实验室，需要 低成本、可操作性强的光谱仪，单台定价 12000-15000 元；第二类为工业质检市场， 纺织、印刷、涂料行业的颜色在线检测需求，单台定价 20000-30000 元；第三类为 消费电子融合方向，与手机端 APP 结合，面向个人用户，定价 10000 元以内。
2. 产品包装

产品设计风格在视觉上与品牌形象保持高度一致，呈现精密仪器的专业感与科 技感，使消费者能够快速识别产品系列归属。包装正面可开设透明亚克力观察窗， 令用户在开箱前即可感受到产品的工艺质感。包装背面以简洁的光路示意图配合文 字说明，直观呈现产品的功能优势与技术创新点

3.推广渠道策略

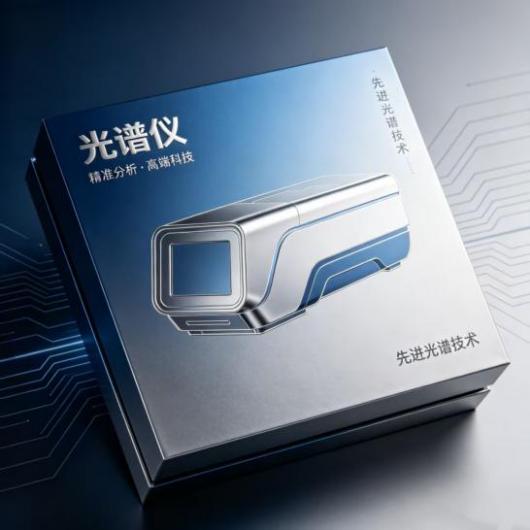
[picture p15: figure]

（1）学术渗透：在全国光学/仪器类学术会议设展位演示，借助学术口碑驱动 高校采购决策；

图 26.产品外包装图

创

意

策

划

方

案

（2）线上直营：建立官网+京东/淘宝旗舰店，提供在线技术文档、开源驱动 代码下载；
（3）高校代理：与各地区高校仪器设备代理商合作，利用其现有教育采购渠 道；
（4）KOL 合作：联系知乎光学/仪器类创作者进行产品评测视频投放，覆盖

高校学生与科研人员群体。
4. 商业模式设计

采用"硬件+软件+服务"三层盈利模式：硬件层：设备销售（基础款 19999 元， 专业款 29999 元）；软件层：数据分析订阅服务；服务层：为高校/企业提供专项

应用定制，项目制报价。
5. 带动就业前景

项目产业化后，预计在光学加工、精密机械、电子硬件、嵌入式软件、数据算 法、市场销售等方向形成多岗位就业需求。初期可直接带动 20—30 人就业；规模 化后直接就业岗位可扩展至 100 人以上，同时带动光学元件供应商、加工外协等上 下游就业约 50 人。产品面向高校开放开发接口，可吸引在校生基于本平台开展毕

业设计与创新创业项目，间接带动学生就业创业生态。

区赛 专家 评定 成绩 | 区赛评委得分： 区赛推荐排名：
组委 会意 见 | 组委会负责人（电子签名有效）： 年 月 日

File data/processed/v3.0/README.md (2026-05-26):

# V3.0 数据处理

处理入口：`scripts/process_v3_tcd1304.py`

主要结果优先看：

1. `reports/processing_report.md`
2. `data/02_group_means/all_group_means_smoothed_normalized_wide.csv`
3. `data/04_quality_control/group_repeatability_stats.csv`
4. `figures/group_means/group_mean_smoothed_normalized_overlay.svg`
5. `final_comparison/V3.0_色卡最终对比图_平滑归一化.svg`
6. `wavelength_calibration_405_780/405_780_线性波长标定公式.csv`

当前脚本默认从同级数据目录推导输入路径。若移动目录或只复制脚本，请同步调整 `INPUT_FOLDER` 和目录层级。

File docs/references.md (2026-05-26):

# References

本仓库不直接再分发参考文献 PDF，以避免版权问题。

已参考资料：

- 施仁杰，光纤光谱仪光学系统设计、建模与仿真。

后续建议补充 DOI、出版社链接或公开可访问链接。

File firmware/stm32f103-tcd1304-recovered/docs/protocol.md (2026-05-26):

# 串口协议与积分时间表

## 串口参数

- 外设：USART1
- 波特率：921600
- 数据位：8
- 校验：无
- 停止位：1

## 上位机命令

| 命令 | 功能 | 单片机返回 |
|---:|---|---|
| `0xA1` | 读取完整 12 位数据 | 3648 点，每点 2 字节，低字节在前，共 7296 字节 |
| `0xA2` | 读取完整 8 位数据 | 3648 点，每点 1 字节，共 3648 字节 |
| `0xA3` | 读取摘要数据 | 12 字节，首字节 `0xFE` |
| `0xB1`-`0xD8` | 设置积分时间 | 不返回数据，单片机重启采集时序 |

## `0xA3` 摘要帧

格式：

```text
FE
max_pos_high100 max_pos_low100
min_pos_high100 min_pos_low100
average_high100 average_low100
max_value_high100 max_value_low100
min_value_high100 min_value_low100
checksum
```

其中 `high100 = value / 100`，`low100 = value % 100`。

`checksum` 是前面 5 个数拆成 base-100 后 10 个字节的累加低 8 位。

## 积分时间命令

积分时间根据反汇编中的定时参数推算：

```text
integration_us = timing_a * timing_c / 72
```

| 命令 | 显示时间 | timing_b | timing_c | timing_a |
|---:|---:|---:|---:|---:|
| `0xB1` | 10 us | 15000 | 36 | 20 |
| `0xB2` | 20 us | 15000 | 36 | 40 |
| `0xB3` | 50 us | 15000 | 36 | 100 |
| `0xB4` | 60 us | 15000 | 36 | 120 |
| `0xB5` | 75 us | 15000 | 36 | 150 |
| `0xB6` | 100 us | 15000 | 36 | 200 |
| `0xB7` | 500 us | 15000 | 36 | 1000 |
| `0xB8` | 1.25 ms | 15000 | 36 | 2500 |
| `0xB9` | 2.5 ms | 15000 | 36 | 5000 |
| `0xBA` | 7.5 ms | 15000 | 36 | 15000 |
| `0xBB` | 10 ms | 20000 | 36 | 20000 |
| `0xBC` | 15 ms | 30000 | 36 | 30000 |
| `0xBD` | 20 ms | 40000 | 36 | 40000 |
| `0xBE` | 25 ms | 50000 | 36 | 50000 |
| `0xBF` | 30 ms | 60000 | 36 | 60000 |
| `0xC0` | 35 ms | 35000 | 72 | 35000 |
| `0xC1` | 40 ms | 40000 | 72 | 40000 |
| `0xC2` | 45 ms | 45000 | 72 | 45000 |
| `0xC3` | 50 ms | 50000 | 72 | 50000 |
| `0xC4` | 55 ms | 55000 | 72 | 55000 |
| `0xC5` | 60 ms | 60000 | 72 | 60000 |
| `0xC6` | 65 ms | 65000 | 72 | 65000 |
| `0xC7` | 70 ms | 35000 | 144 | 35000 |
| `0xC8` | 75 ms | 37500 | 144 | 37500 |
| `0xC9` | 80 ms | 40000 | 144 | 40000 |
| `0xCA` | 85 ms | 42500 | 144 | 42500 |
| `0xCB` | 90 ms | 45000 | 144 | 45000 |
| `0xCC` | 94.4 ms | 47200 | 144 | 47200 |
| `0xCD` | 100 ms | 50000 | 144 | 50000 |
| `0xCE` | 200 ms | 50000 | 288 | 50000 |
| `0xCF` | 300 ms | 37500 | 576 | 37500 |
| `0xD0` | 400 ms | 25000 | 1152 | 25000 |
| `0xD1` | 500 ms | 31250 | 1152 | 31250 |
| `0xD2` | 600 ms | 37500 | 1152 | 37500 |
| `0xD3` | 700 ms | 43750 | 1152 | 43750 |
| `0xD4` | 800 ms | 50000 | 1152 | 50000 |
| `0xD5` | 900 ms | 56250 | 1152 | 56250 |
| `0xD6` | 1 s | 62500 | 1152 | 62500 |
| `0xD7` | 2 s | 62500 | 2304 | 62500 |
| `0xD8` | 3 s | 46875 | 4608 | 46875 |

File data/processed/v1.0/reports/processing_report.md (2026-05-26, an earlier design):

# V1.0 TCD1304 数据处理报告

## 数据理解

- 原始目录：`data/V1.0采集数据`
- 本次处理文件数：41；其中色卡文件 35 个，镜片/参考文件 6 个。
- 色卡编号：1, 2, 3, 4, 6, 7, 8。当前目录没有编号 5 的色卡文件。
- 每个文件包含 `Pixel, ADC, VoltageV` 三列；本批数据实际像素记录为 3647 行，末端像素为 3647。
- 前 20 行存在读出起始瞬态/暗平台，本次保留其统计信息，但不进入有效光谱曲线。

## 处理流程

1. 按文件名解析 `A-B`：`A` 为色卡编号，`B` 为重复检测组别。
2. 用每个文件前 16 个高平台点的中位数估计 `dark_adc`。
3. 将 ADC 转为光强方向信号：`IntensityADC = dark_adc - ADC`。这样曲线越高表示 TCD1304 接收到的反射光越强。
4. 丢弃前 20 行后，对光强曲线做 9 点中值滤波，再做 151 点、3 阶 Savitzky-Golay 平滑。
5. 对每条曲线生成最大值归一化结果，用于比较谱形；对同一色卡的 5 次检测生成均值、标准差和变异系数。
6. 对编号镜片参考先做一致性筛选，相关性阈值为 0.98；用通过筛选的平滑光强中位数作为系统参考，生成 `ReferenceCorrectedRatio = sample / reference`。未通过筛选或未编号的 `镜片` 文件只进入 QC，不参与参考均值。

## 输出结构

- `data/00_manifest/file_manifest.csv`：文件清单、解析出的色卡编号/重复编号、哈希和行数。
- `data/01_cleaned_per_file/`：每个文件的暗校正、平滑、归一化曲线。
- `data/02_group_means/`：每个色卡的组均值曲线和宽表。
- `data/03_reference_corrected/`：镜片参考谱和参考校正后的相对反射曲线。
- `data/04_quality_control/`：文件级 QC、组内重复性、组间相关矩阵、参考候选统计。
- `figures/`：对应 SVG 图，浏览器可直接打开。
- `scripts/process_v1_tcd1304.py`：可重复运行的处理脚本。

## QC 摘要

| 色卡 | 重复数 | 组内平均相关 | 平均点位 CV | 平均光强 ADC | 平滑峰值像素 |
|---:|---:|---:|---:|---:|---:|
| 1 | 5 | 0.999897 | 0.002426 | 1359.01 | 3407.8 |
| 2 | 5 | 0.999954 | 0.001499 | 1390.78 | 3401.8 |
| 3 | 5 | 0.999958 | 0.002319 | 1301.06 | 3403.0 |
| 4 | 5 | 0.999934 | 0.002137 | 1225.33 | 3399.6 |
| 6 | 5 | 0.999941 | 0.001723 | 1275.78 | 3408.0 |
| 7 | 5 | 0.999945 | 0.002257 | 1296.04 | 3405.2 |
| 8 | 5 | 0.999936 | 0.001522 | 1213.07 | 3405.6 |

发现可能完全重复的 ADC 序列：card01_rep03 == card01_rep04; card01_rep04 == card01_rep03; card08_rep01 == card08_rep02; card08_rep02 == card08_rep01

以下镜片参考未进入最终参考均值，建议复测或检查光路：lens_rep04(0.346), lens_rep05(0.902), lens_unlabelled(-0.278)

## 使用建议

- 当前结果仍是 `Pixel` 坐标，不是波长坐标。要得到真正的光谱反射率，需要用汞灯、氖灯、激光或已知窄带滤光片建立 `Pixel -> wavelength` 标定。
- 建议之后每批采集同时保存暗场（关光源/遮光）和白板参考（标准白板或稳定漫反射白片）。暗场应从每个像素扣除，白板参考用于绝对或相对反射率归一化。
- 编号镜片参考里存在一致性偏低的曲线时，优先检查光路位置、色卡/镜片放置角度、积分时间和光源稳定性。
- 组内重复性已经很高，说明色卡采样本身可重复；下一步提升有效性的重点是参考测量和波长标定。

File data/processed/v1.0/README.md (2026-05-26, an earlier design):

# V1.0 数据处理

处理入口：`scripts/process_v1_tcd1304.py`

主要结果优先看：

1. `reports/processing_report.md`
2. `data/02_group_means/all_group_means_smoothed_normalized_wide.csv`
3. `data/03_reference_corrected/all_group_means_reference_corrected_wide.csv`
4. `figures/group_means/group_mean_smoothed_normalized_overlay.svg`
5. `figures/reference_corrected/group_mean_reference_corrected_overlay.svg`

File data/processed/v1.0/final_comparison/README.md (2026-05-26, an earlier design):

# V1.0 色卡最终对比结果

优先打开：

1. `V1.0_色卡最终对比表.xlsx`：所有色卡曲线在一个 Excel 文件里，包含曲线表、差异指标和图表。
2. `V1.0_色卡最终对比图_平滑归一化.png`：所有色卡平滑归一化曲线叠加图。
3. `V1.0_色卡最终对比图_参考校正相对反射.png`：所有色卡参考校正相对反射曲线叠加图。

CSV：

- `V1.0_色卡组均值曲线_同表_平滑归一化.csv`：Pixel + 每个色卡一列，适合看谱形差异。
- `V1.0_色卡组均值曲线_同表_参考校正.csv`：Pixel + 每个色卡一列，适合看参考校正后的相对反射差异。
- `V1.0_色卡曲线差异指标.csv`：峰值、面积、高低像素段比值等摘要指标。

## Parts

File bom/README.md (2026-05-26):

# BOM

- `lens-materials.xlsx`: 镜片材料采购清单。

该清单来自原型阶段，用于复现时请重新确认供应商、规格、尺寸、镀膜、库存和价格。

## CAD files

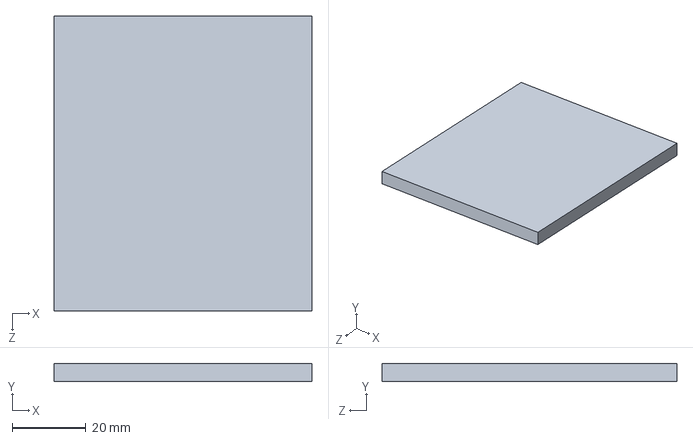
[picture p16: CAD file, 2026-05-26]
hardware/mechanical/step/隔离板2.STEP
70.0 x 5.00 x 80.0 mm

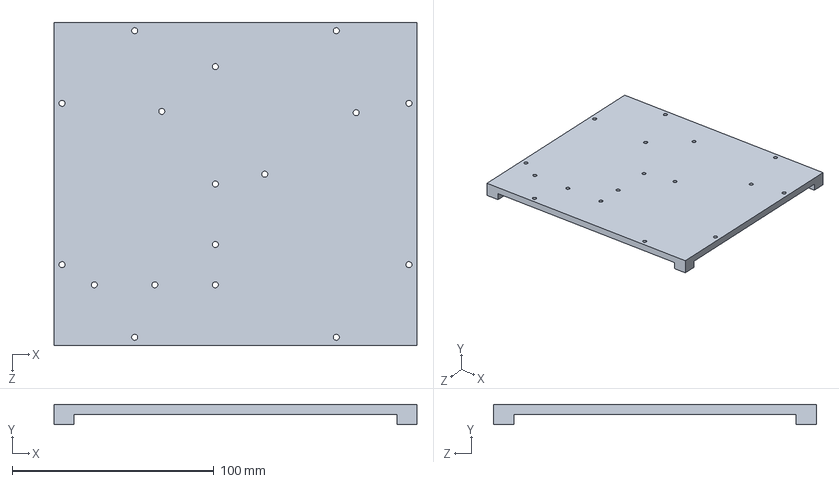
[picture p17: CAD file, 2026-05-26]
hardware/mechanical/step/支撑.STEP
180.0 x 10.0 x 160.0 mm

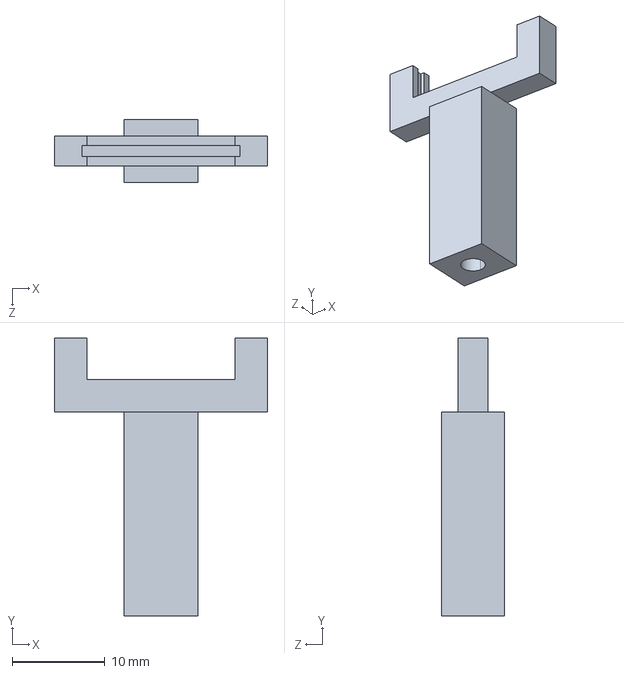
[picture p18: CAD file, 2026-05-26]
hardware/mechanical/step/偏光夹.STEP
23.0 x 30.0 x 6.80 mm

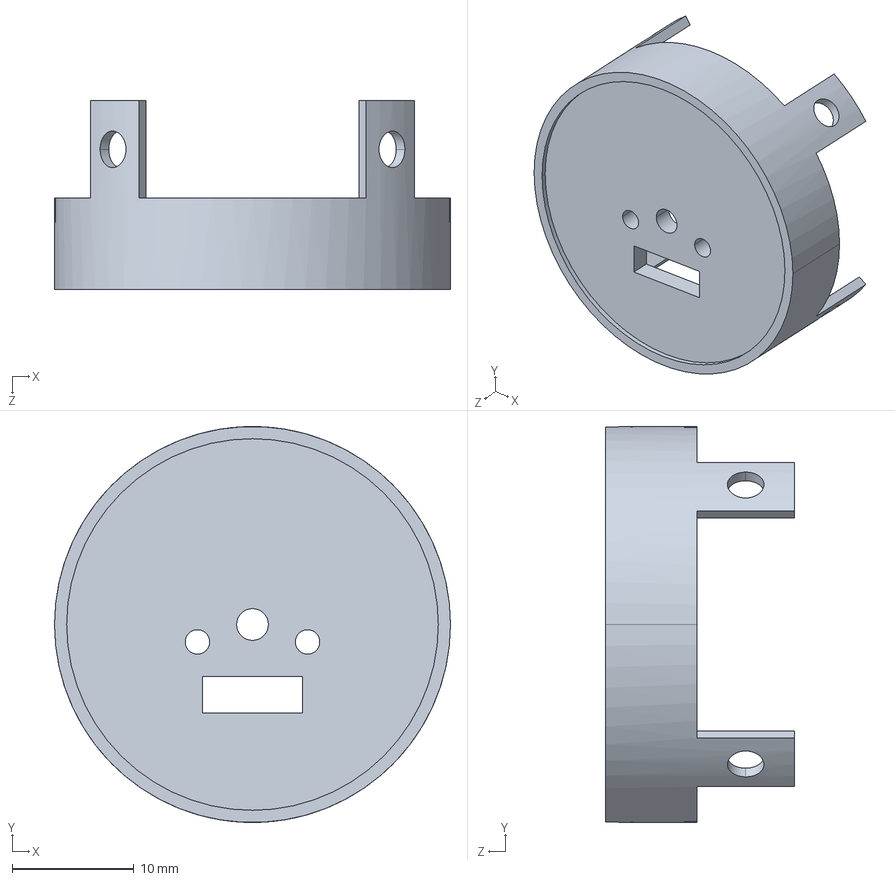
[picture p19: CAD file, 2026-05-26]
hardware/mechanical/step/LED固件.STEP
32.5 x 32.5 x 15.5 mm

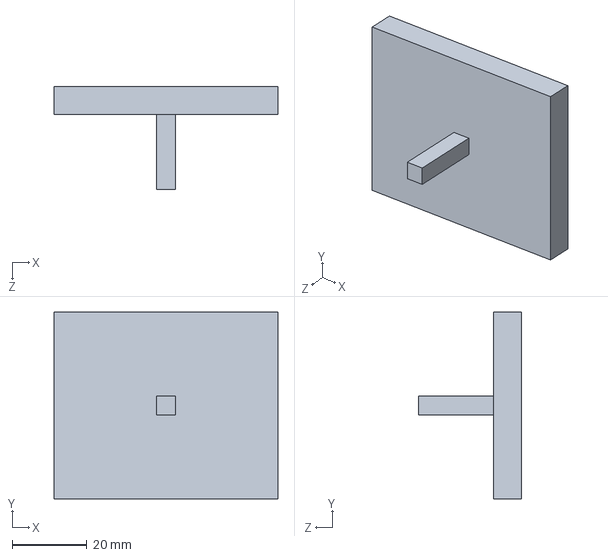
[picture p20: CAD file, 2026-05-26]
hardware/mechanical/step/测试更换模块.STEP
59.8 x 49.8 x 27.4 mm

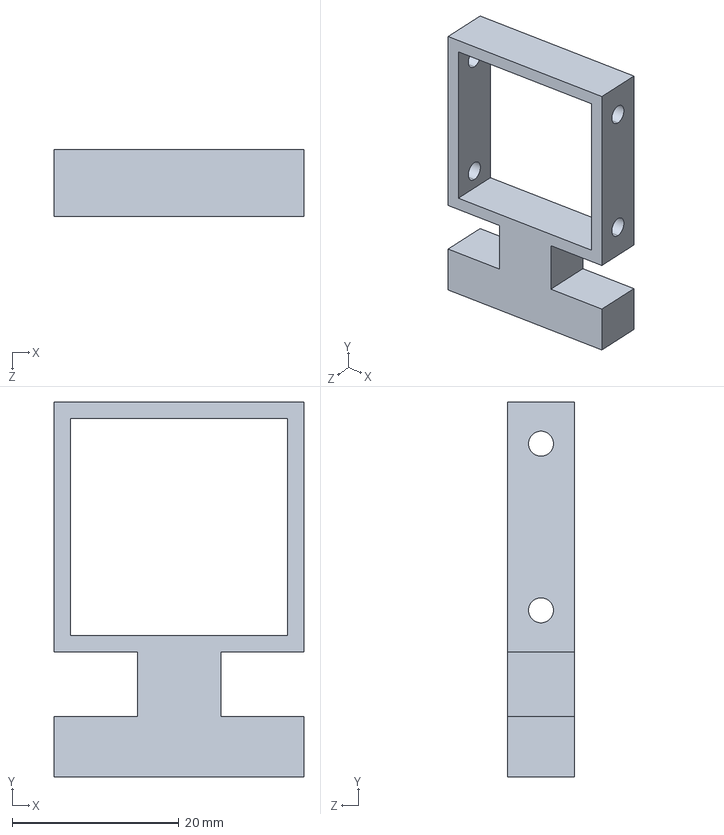
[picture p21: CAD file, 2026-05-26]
hardware/mechanical/step/方形镜架.STEP
30.0 x 45.0 x 8.00 mm

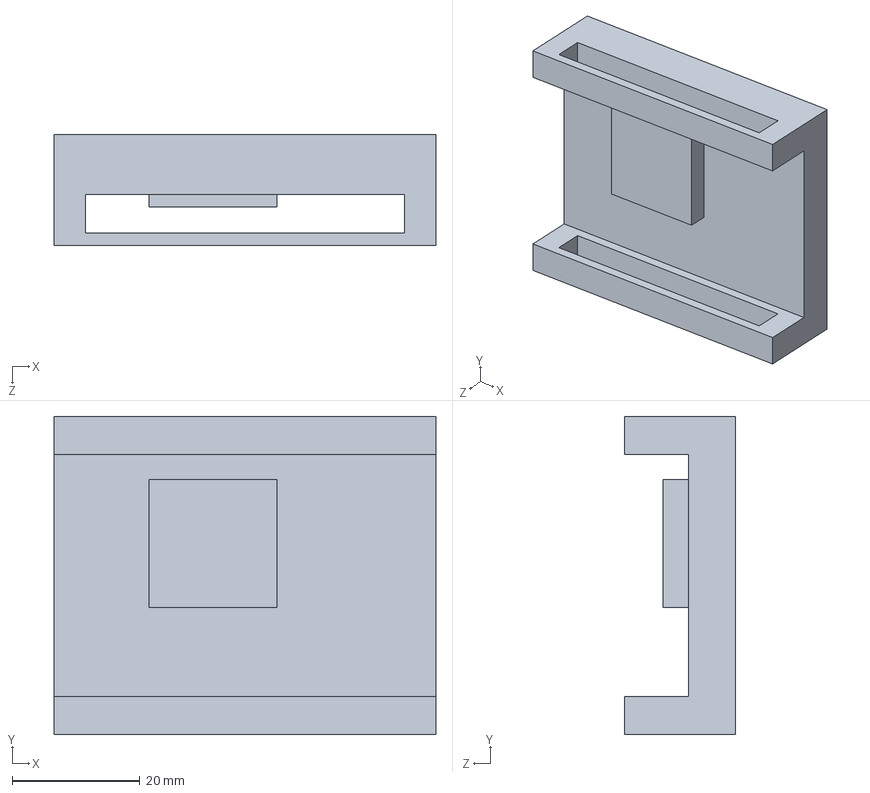
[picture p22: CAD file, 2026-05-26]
hardware/mechanical/step/可重复使用测试模块.STEP
59.8 x 49.8 x 17.4 mm

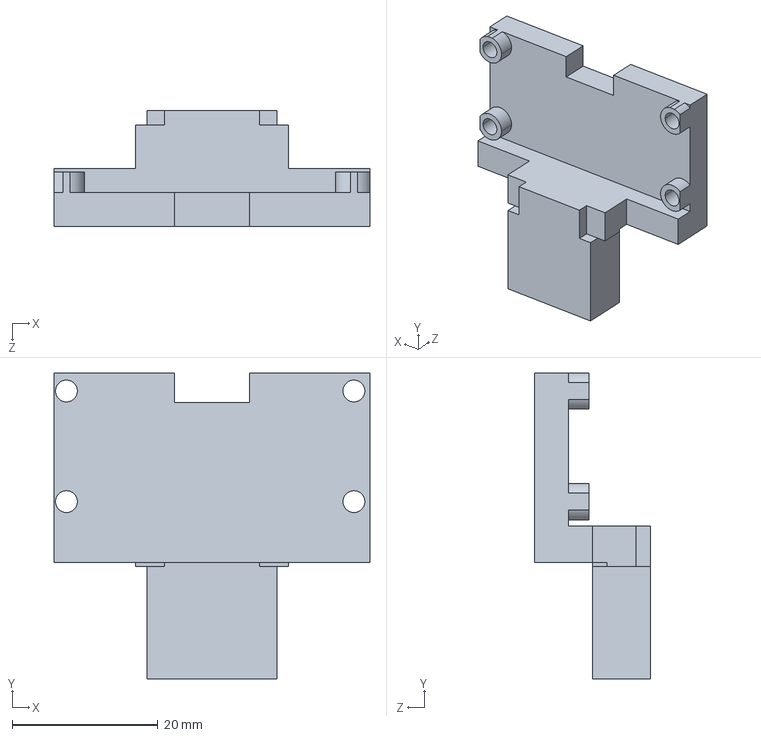
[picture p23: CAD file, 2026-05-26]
hardware/mechanical/step/TCD1304镜架.STEP
43.4 x 42.0 x 16.0 mm

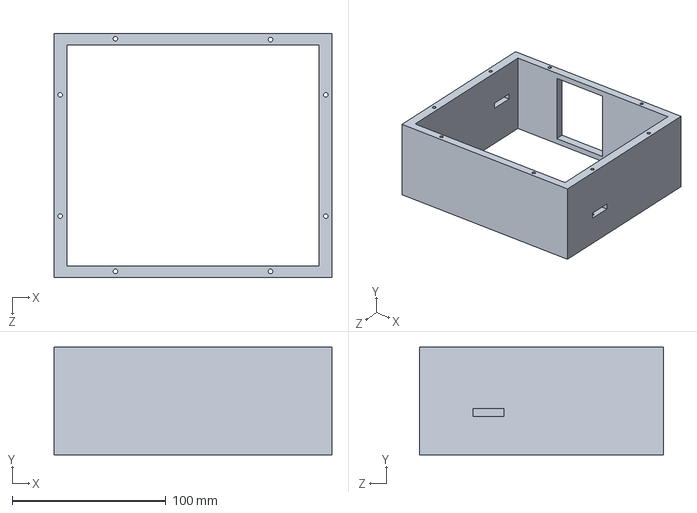
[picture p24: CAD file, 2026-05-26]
hardware/mechanical/step/光谱仪外壳.STEP
180.9 x 70.0 x 158.8 mm

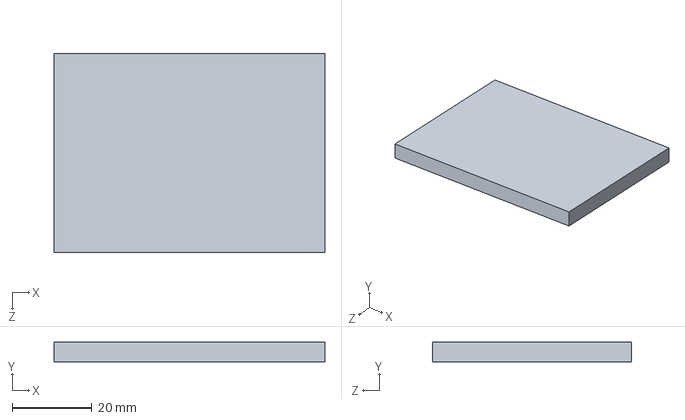
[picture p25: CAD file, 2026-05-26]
hardware/mechanical/step/零件1.STEP
68.0 x 5.00 x 50.0 mm

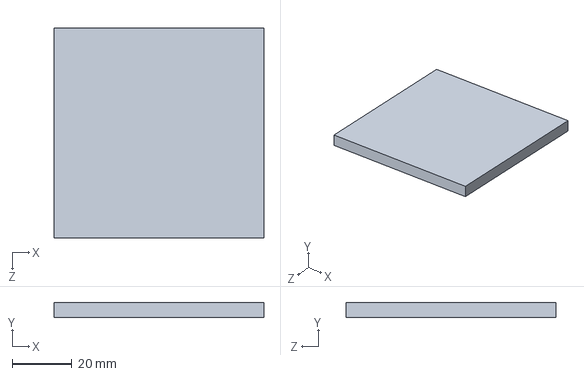
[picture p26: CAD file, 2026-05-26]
hardware/mechanical/step/隔离板1.STEP
70.0 x 5.00 x 70.0 mm

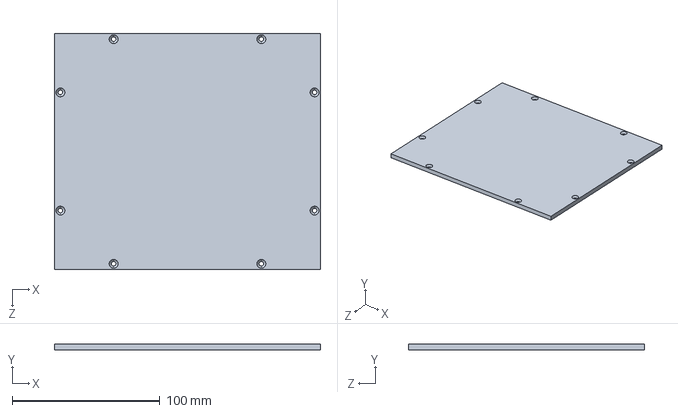
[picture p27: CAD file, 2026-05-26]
hardware/mechanical/step/顶盖.STEP
180.0 x 4.00 x 160.0 mm

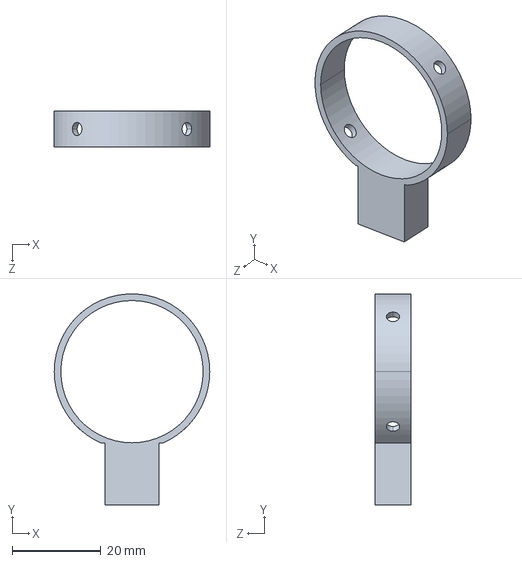
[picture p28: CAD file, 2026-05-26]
hardware/mechanical/step/圆形镜片架.STEP
35.0 x 47.5 x 8.00 mm

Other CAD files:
hardware/mechanical/step/更换测量板.STEP
hardware/mechanical/step/支撑板.STEP

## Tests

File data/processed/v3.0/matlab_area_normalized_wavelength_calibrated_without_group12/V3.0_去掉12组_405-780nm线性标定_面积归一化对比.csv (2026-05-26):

Wavelength_nm | Group01_AreaNormShape | Group02_AreaNormShape | Group03_AreaNormShape | Group04_AreaNormShape | Group05_AreaNormShape | Group06_AreaNormShape | Group07_AreaNormShape | Group08_AreaNormShape | Group09_AreaNormShape | Group10_AreaNormShape | Group11_AreaNormShape
405.028362554401 | 1.02590922496574 | 1 | 1.0163277831559 | 1.02804139361377 | 1.00898889216219 | 1.02799041716275 | 1.01695957725749 | 1.03991570402276 | 1.0188068901219 | 1.01404583196796 | 1.01372182327301
405.072523960818 | 1.02589261322001 | 1 | 1.01629245527211 | 1.02803298320671 | 1.00898095867495 | 1.02798574279995 | 1.01695385475757 | 1.03988436936425 | 1.01878412017859 | 1.01402785259926 | 1.01372211645495
405.116685367234 | 1.0258757413782 | 1 | 1.01625687866481 | 1.02802450976815 | 1.00897310919875 | 1.02798125993808 | 1.01694823051569 | 1.03985259042708 | 1.0187611530845 | 1.0140098405227 | 1.01372232096648
405.160846773648 | 1.02585863678733 | 1 | 1.01622109599496 | 1.0280159815829 | 1.00896538179779 | 1.0279770425863 | 1.01694273653917 | 1.03982036947555 | 1.0187380207403 | 1.01399181914105 | 1.01372245382143
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

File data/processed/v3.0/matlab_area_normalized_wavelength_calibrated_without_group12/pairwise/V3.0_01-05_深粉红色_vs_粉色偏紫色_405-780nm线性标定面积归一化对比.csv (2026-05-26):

Wavelength_nm | Group01_AreaNormShape | Group05_AreaNormShape | Difference_A_minus_B
405.028362554401 | 1.02590922496574 | 1.00898889216219 | 0.0169203328035501
405.072523960818 | 1.02589261322001 | 1.00898095867495 | 0.0169116545450598
405.116685367234 | 1.0258757413782 | 1.00897310919875 | 0.0169026321794501
405.160846773648 | 1.02585863678733 | 1.00896538179779 | 0.01689325498954
405.205008180065 | 1.02584131405586 | 1.00895785678366 | 0.0168834572722001
405.249169586481 | 1.02582378278414 | 1.00895057625767 | 0.0168732065264701
405.293330992898 | 1.02580605608441 | 1.00894353954321 | 0.0168625165412
405.337492399315 | 1.02578815182182 | 1.008936710934 | 0.01685144088782
405.381653805729 | 1.02577009348202 | 1.00893002639259 | 0.01684006708943
405.425815212145 | 1.02575191249105 | 1.0089234112149 | 0.01682850127615
405.469976618562 | 1.02573365528707 | 1.00891686926176 | 0.0168167860253099
405.514138024978 | 1.02571536448664 | 1.00891042581105 | 0.01680493867559
405.558299431395 | 1.02569707001698 | 1.00890406041712 | 0.0167930095998601
405.602460837809 | 1.02567878900601 | 1.00889780560098 | 0.0167809834050299
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

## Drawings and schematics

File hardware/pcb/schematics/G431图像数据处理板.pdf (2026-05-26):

STM32G431最小系统 | ESP32-S3-Touch-lcd-2触摸

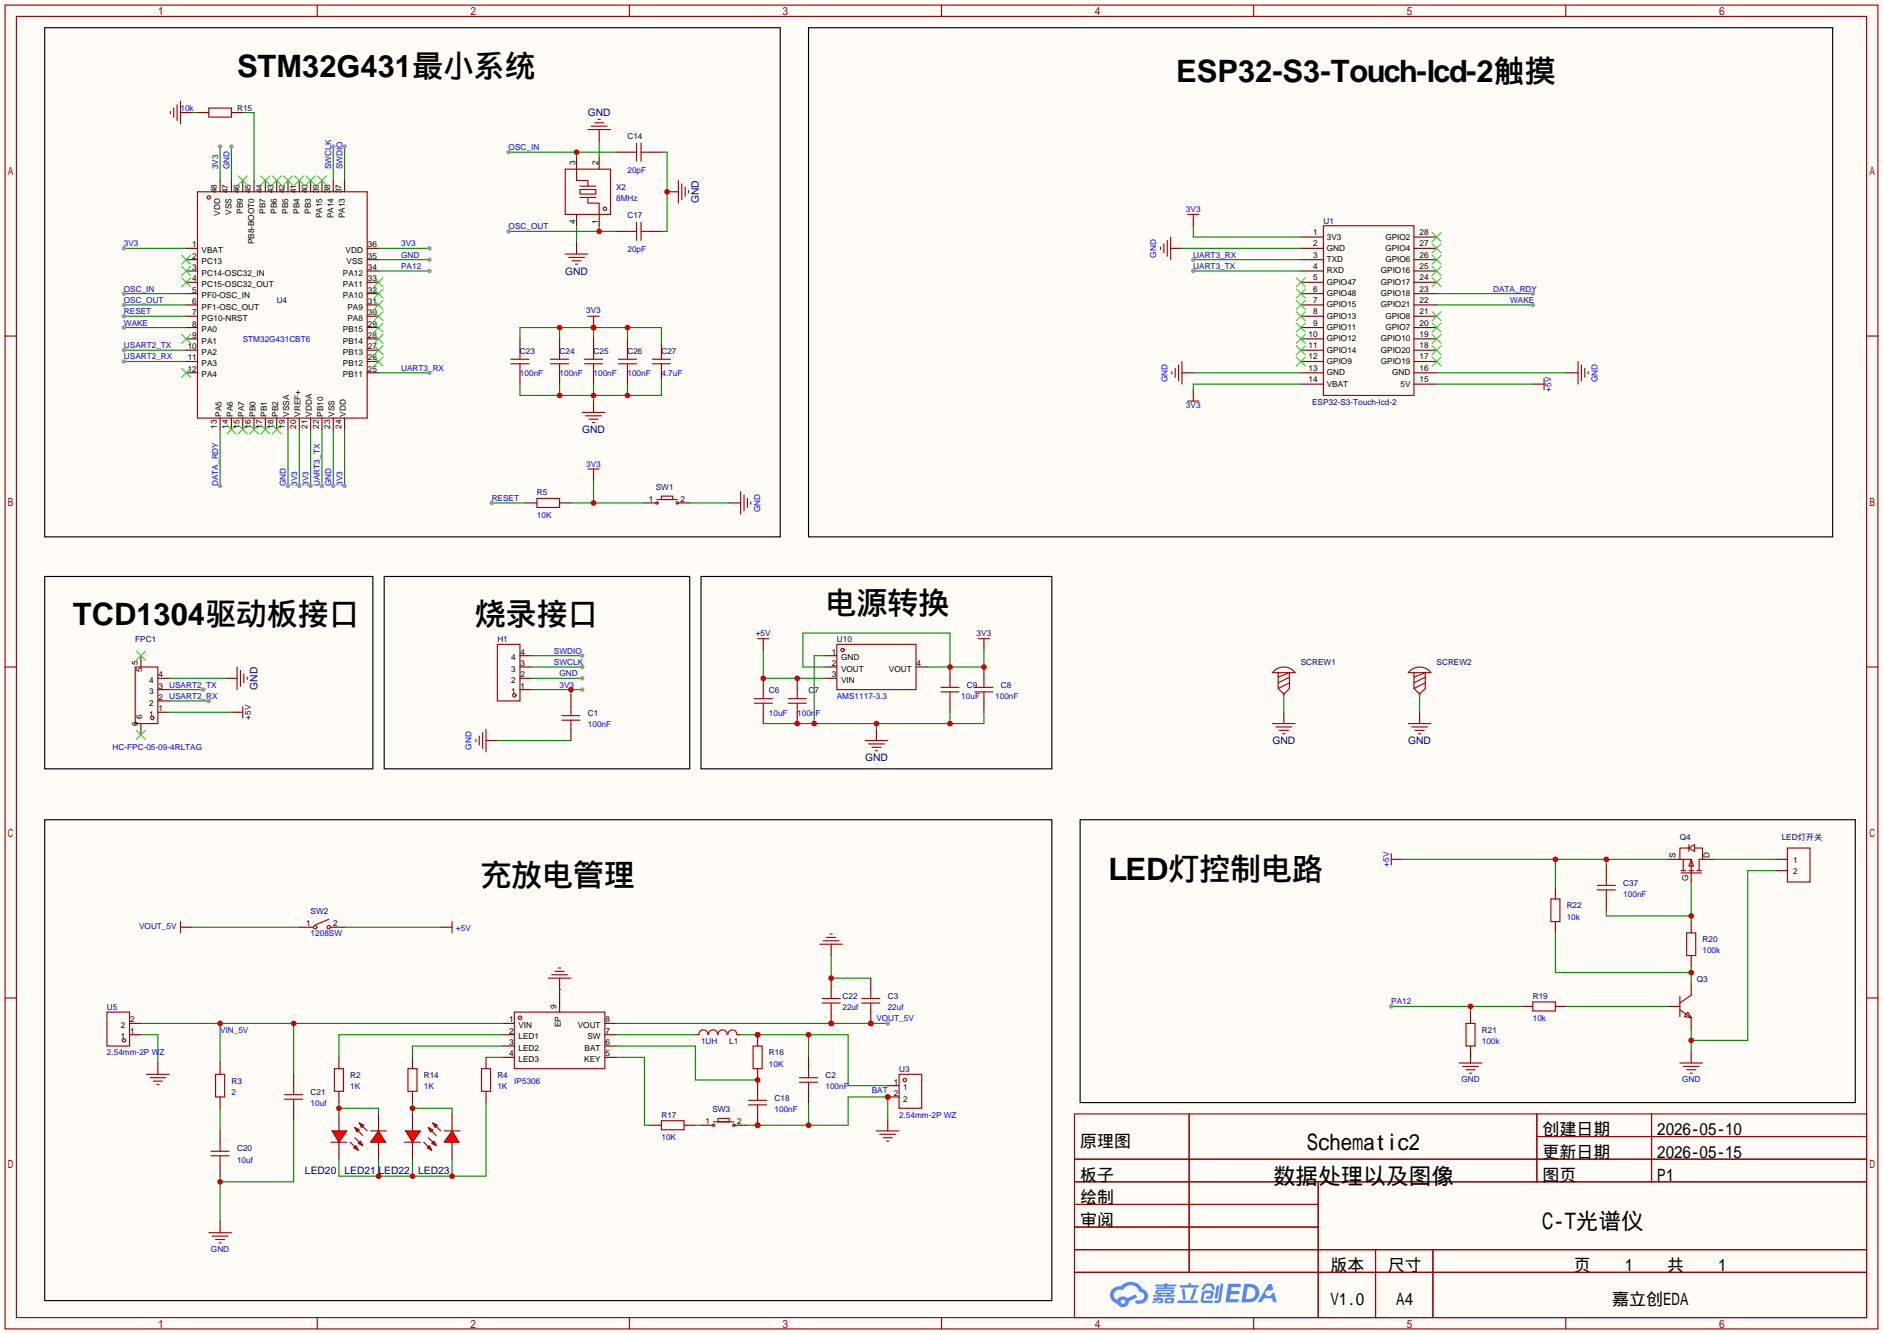
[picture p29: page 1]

原理图 | Schematic2 | 创建日期 | 2026-05-10
板子 | 数据处理以及图像 | 图页 | P1
绘制 | | C-T光谱仪
审阅

更新日期 | 2026-05-15

V1.0 | A4 | 嘉立创EDA

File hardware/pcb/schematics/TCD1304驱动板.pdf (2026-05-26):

# 线性稳压电源

滤波电容 | 晶振

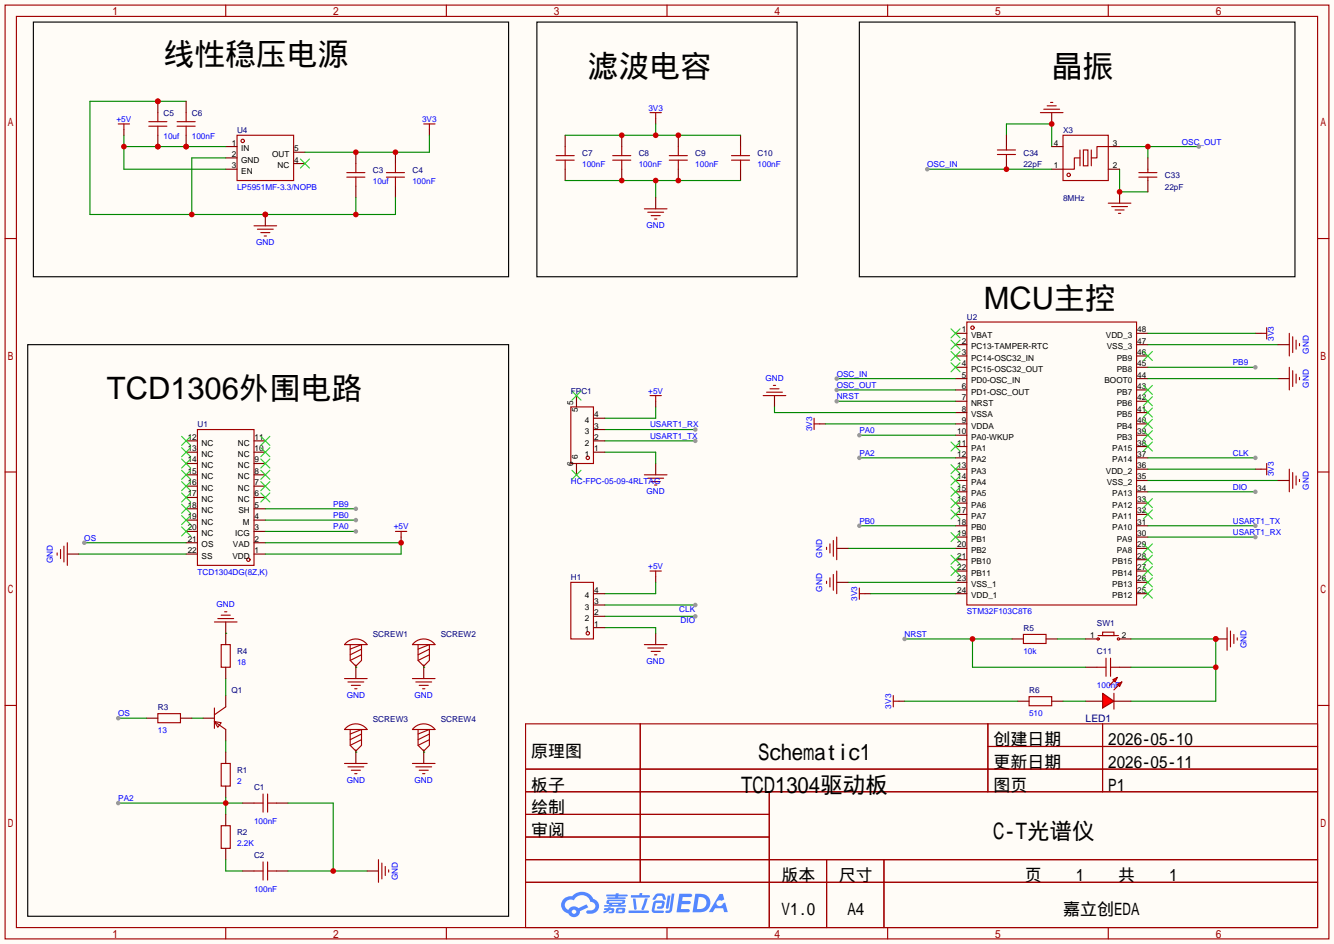
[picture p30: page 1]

原理图 | Schematic1 | 创建日期 | 2026-05-10
板子 | TCD1304驱动板 | 图页 | P1
绘制 | | C-T光谱仪
审阅

更新日期 | 2026-05-11

V1.0 | A4 | 嘉立创EDA

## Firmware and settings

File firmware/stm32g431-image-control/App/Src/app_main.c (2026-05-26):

#include "app_main.h"

#include <stdio.h>
#include <string.h>

#include "app_config.h"
#include "app_group_stats.h"
#include "app_pipeline.h"
#include "app_types.h"
#include "bsp_uart.h"

static AppFrame g_frame;
static uint32_t g_packet_seq = 0U;
static uint8_t g_next_replicate_id = 1U;
static char g_link_rx_line[APP_UART_RX_LINE_MAX];
static uint16_t g_link_rx_len = 0U;
static uint8_t g_link_rx_overflow = 0U;
static uint8_t g_last_replicate_id = 0U;
static uint16_t g_last_valid_count = 0U;

typedef struct
{
  uint8_t valid;
  uint8_t group_stats_valid;
  uint8_t group_id;
  uint8_t replicate_id;
  uint16_t point_count;
  uint16_t valid_count;
  uint16_t first_pixel;
  uint16_t curve_start_pixel;
  uint16_t curve_count;
  uint16_t peak_pixel_raw;
  uint16_t peak_pixel_smooth;
  float dark_adc;
  float intensity_mean;
  float intensity_max;
  AppGroupStats group_stats;
  uint16_t curve_q15[APP_DOWNSAMPLED_POINTS_MAX];
} AppDisplayPacket;

static AppDisplayPacket g_pending_packet;
static void queue_frame_packet(const AppFrame *frame, const AppGroupStats *stats);
static void emit_link_status(const char *token);
static void handle_link_command(const char *line);
static void poll_link_commands(void);

static void process_ready_frame(AppFrame *frame)
{
  const AppGroupStats *stats;
  uint8_t i;

  if (frame == NULL)
  {
    return;
  }

  AppGroupStats_Accumulate(frame);

  stats = NULL;
  for (i = 0U; i < AppGroupStats_GetCount(); ++i)
  {
    stats = AppGroupStats_GetByIndex(i);
    if ((stats != NULL) && (stats->group_id == frame->group_id))
    {
      break;
    }
  }

  queue_frame_packet(frame, stats);
}

static void copy_frame_to_packet(const AppFrame *frame, const AppGroupStats *stats)
{
  if (frame == NULL)
  {
    return;
  }

  memset(&g_pending_packet, 0, sizeof(g_pending_packet));
  g_pending_packet.valid = 1U;
  g_pending_packet.group_id = frame->group_id;
  g_pending_packet.replicate_id = frame->replicate_id;
  g_pending_packet.point_count = frame->point_count;
  g_pending_packet.valid_count = frame->valid_count;
  g_pending_packet.first_pixel = frame->first_pixel;
  g_pending_packet.curve_start_pixel = (uint16_t)(frame->first_pixel + APP_SKIP_FIRST_ROWS);
  g_pending_packet.curve_count = frame->downsampled_count;
  g_pending_packet.peak_pixel_raw = frame->peak_pixel_raw;
  g_pending_packet.peak_pixel_smooth = frame->peak_pixel_smooth;
  g_pending_packet.dark_adc = frame->dark_adc;
  g_pending_packet.intensity_mean = frame->intensity_mean;
  g_pending_packet.intensity_max = frame->intensity_max;
  g_last_replicate_id = frame->replicate_id;
  g_last_valid_count = frame->valid_count;
  memcpy(g_pending_packet.curve_q15,
         frame->smooth_norm_q15,
         (uint32_t)frame->downsampled_count * sizeof(frame->smooth_norm_q15[0]));

  if (stats != NULL)
  {
    g_pending_packet.group_stats_valid = 1U;
    g_pending_packet.group_stats = *stats;
  }
}

static void emit_info_line(const char *prefix, const char *text)
{
  char line[APP_UART_TX_LINE_MAX];

  snprintf(line, sizeof(line), "%s %s\r\n", prefix, text);
  (void)BSP_UART_OutputWriteString(line);
}

static void emit_link_status(const char *token)
{
  char line[APP_UART_TX_LINE_MAX];
  const uint8_t replicate_id = (g_pending_packet.valid != 0U) ? g_pending_packet.replicate_id : g_last_replicate_id;
  const uint16_t valid_count = (g_pending_packet.valid != 0U) ? g_pending_packet.valid_count : g_last_valid_count;

  snprintf(line,
           sizeof(line),
            "LINK STATUS T=%s READY=1 WAKE=%u DATA=%u PENDING=%u SEQ=%lu REP=%u VALID=%u\r\n",
            token,
            BSP_UART_IsLinkWakeActive(),
            BSP_UART_IsLinkDataReadyActive(),
            (g_pending_packet.valid != 0U) ? 1U : 0U,
            (unsigned long)g_packet_seq,
            replicate_id,
            valid_count);
  (void)BSP_UART_OutputWriteString(line);
}

static void handle_link_command(const char *line)
{
  static const char kLinkQueryPrefix[] = "LINK? T=";
  const char *token;

  if (line == NULL)
  {
    return;
  }

  if (strncmp(line, kLinkQueryPrefix, sizeof(kLinkQueryPrefix) - 1U) != 0)
  {
    return;
  }

  token = line + (sizeof(kLinkQueryPrefix) - 1U);
  if (token[0] == '\0')
  {
    return;
  }

  emit_link_status(token);
}

static void poll_link_commands(void)
{
  uint8_t byte = 0U;

  while (BSP_UART_LinkTryReadByte(&byte) != 0U)
  {
    if ((byte == '\r') || (byte == '\n'))
    {
      if ((g_link_rx_overflow == 0U) && (g_link_rx_len > 0U))
      {
        g_link_rx_line[g_link_rx_len] = '\0';
        handle_link_command(g_link_rx_line);
      }
      g_link_rx_len = 0U;
      g_link_rx_overflow = 0U;
      continue;
    }

    if (g_link_rx_overflow != 0U)
    {
      continue;
    }

    if (g_link_rx_len < (APP_UART_RX_LINE_MAX - 1U))
    {
      g_link_rx_line[g_link_rx_len++] = (char)byte;
    }
    else
    {
      g_link_rx_len = 0U;
      g_link_rx_overflow = 1U;
    }
  }
}

static void emit_pending_packet(void)
{
  uint16_t i;
  char line[APP_UART_TX_LINE_MAX];

  if (g_pending_packet.valid == 0U)
  {
    return;
  }

  if (BSP_UART_IsLinkWakeActive() == 0U)
  {
    return;
  }

  g_packet_seq++;
  snprintf(line, sizeof(line), "PKT BEGIN SEQ=%lu\r\n", (unsigned long)g_packet_seq);
  (void)BSP_UART_OutputWriteString(line);

  snprintf(line,
           sizeof(line),
           "FRAME G=%u R=%u POINTS=%u VALID=%u FIRST=%u CURVE_FIRST=%u STEP=%u CURVE_COUNT=%u DARK=%.2f PEAK_RAW=%u PEAK_SMOOTH=%u IMEAN=%.2f IMAX=%.2f\r\n",
           g_pending_packet.group_id,
           g_pending_packet.replicate_id,
           g_pending_packet.point_count,
           g_pending_packet.valid_count,
           g_pending_packet.first_pixel,
           g_pending_packet.curve_start_pixel,
           APP_DOWNSAMPLE_STEP,
           g_pending_packet.curve_count,
           g_pending_packet.dark_adc,
           g_pending_packet.peak_pixel_raw,
           g_pending_packet.peak_pixel_smooth,
           g_pending_packet.intensity_mean,
           g_pending_packet.intensity_max);
  (void)BSP_UART_OutputWriteString(line);

  if (g_pending_packet.group_stats_valid != 0U)
  {
    snprintf(line,
             sizeof(line),
             "GROUP G=%u N=%u VALID=%u DCOUNT=%u CV=%.5f CORR_MEAN=%.5f CORR_MIN=%.5f PEAK_MEAN=%.2f PEAK_STD=%.2f\r\n",
             g_pending_packet.group_stats.group_id,
             g_pending_packet.group_stats.replicate_count,
             g_pending_packet.group_stats.valid_count,
             g_pending_packet.group_stats.downsampled_count,
             g_pending_packet.group_stats.mean_point_cv,
             g_pending_packet.group_stats.mean_pair_correlation,
             g_pending_packet.group_stats.min_pair_correlation,
             g_pending_packet.group_stats.mean_peak_pixel,
             g_pending_packet.group_stats.peak_pixel_std);
    (void)BSP_UART_OutputWriteString(line);
  }

  snprintf(line,
           sizeof(line),
           "CURVE_BEGIN FIRST=%u STEP=%u COUNT=%u\r\n",
           g_pending_packet.curve_start_pixel,
           APP_DOWNSAMPLE_STEP,
           g_pending_packet.curve_count);
  (void)BSP_UART_OutputWriteString(line);

  for (i = 0U; i < g_pending_packet.curve_count; ++i)
  {
    uint16_t pixel = (uint16_t)(g_pending_packet.curve_start_pixel + i * APP_DOWNSAMPLE_STEP);
    snprintf(line,
             sizeof(line),
             "CURVE %u %u\r\n",
             pixel,
             g_pending_packet.curve_q15[i]);
    (void)BSP_UART_OutputWriteString(line);
  }

  (void)BSP_UART_OutputWriteString("CURVE_END\r\n");
  (void)BSP_UART_OutputWriteString("PKT END\r\n");

  g_pending_packet.valid = 0U;
  BSP_UART_SetLinkDataReady(0U);
}

static void queue_frame_packet(const AppFrame *frame, const AppGroupStats *stats)
{
  copy_frame_to_packet(frame, stats);
  BSP_UART_SetLinkDataReady(1U);
  emit_pending_packet();
}

void App_OnFrameText(const char *frame_text)
{
  char error_text[48];
  AppPipelineStatus status;

  status = AppPipeline_ProcessAsciiLine(frame_text, &g_frame, error_text, sizeof(error_text));
  if (status == APP_PIPELINE_COLLECTING)
  {
    return;
  }
  if (status != APP_PIPELINE_READY)
  {
    emit_info_line("ERR", error_text);
    return;
  }

  process_ready_frame(&g_frame);
}

void App_OnFrameBinary(const uint8_t *frame_data, uint16_t frame_size)
{
  char error_text[48];
  AppPipelineStatus status;

  status = AppPipeline_ProcessF103Frame12Bit(frame_data,
                                             frame_size,
                                             APP_F103_DEFAULT_GROUP_ID,
                                             g_next_replicate_id,
                                             &g_frame,
                                             error_text,
                                             sizeof(error_text));
  if (status != APP_PIPELINE_READY)
  {
    emit_info_line("ERR", error_text);
    return;
  }

  process_ready_frame(&g_frame);
  g_next_replicate_id++;
  if (g_next_replicate_id > APP_GROUP_REPLICATE_MAX)
  {
    g_next_replicate_id = 1U;
    AppGroupStats_Init();
  }
}

void App_Init(void)
{
  BSP_UART_Init();
  AppPipeline_Init();
  AppGroupStats_Init();
  memset(&g_pending_packet, 0, sizeof(g_pending_packet));
  g_link_rx_len = 0U;
  g_link_rx_overflow = 0U;
  g_last_replicate_id = 0U;
  g_last_valid_count = 0U;
  BSP_UART_SetLinkDataReady(0U);

  emit_info_line("INFO", "STM32G431 image-control ready");
}

void App_Loop(void)
{
  uint8_t request = APP_F103_REQUEST_12BIT_CMD;

  emit_pending_packet();
  poll_link_commands();

  if (g_pending_packet.valid != 0U)
  {
    return;
  }

#if (APP_INPUT_MODE_F103_BINARY != 0U)
  if (BSP_UART_InputWrite(&request, 1U, 20U) != HAL_OK)
  {
    emit_info_line("ERR", "f103 request failed");
    return;
  }

  if (BSP_UART_InputReceive((uint8_t *)g_frame.sample_x2, sizeof(g_frame.sample_x2), APP_F103_RX_TIMEOUT_MS) != HAL_OK)
  {
    emit_info_line("ERR", "f103 frame timeout");
    return;
  }

  App_OnFrameBinary((const uint8_t *)g_frame.sample_x2, (uint16_t)sizeof(g_frame.sample_x2));
#else
  {
    uint8_t byte = 0U;
    static char g_rx_line[APP_UART_RX_LINE_MAX];
    static uint16_t g_rx_len = 0U;

    if (BSP_UART_InputReceiveByte(&byte, 10U) != HAL_OK)
    {
      return;
    }

    if ((byte == '\r') || (byte == '\n'))
    {
      if (g_rx_len > 0U)
      {
        g_rx_line[g_rx_len] = '\0';
        App_OnFrameText(g_rx_line);
        g_rx_len = 0U;
      }
      return;
    }

    if (g_rx_len < (APP_UART_RX_LINE_MAX - 1U))
    {
      g_rx_line[g_rx_len++] = (char)byte;
    }
    else
    {
      g_rx_len = 0U;
      emit_info_line("ERR", "line too long");
    }
  }
#endif
}

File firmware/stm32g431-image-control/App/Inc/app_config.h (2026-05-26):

#ifndef APP_CONFIG_H
#define APP_CONFIG_H

#define APP_FRAME_POINTS_MAX        3648U
#define APP_SKIP_FIRST_ROWS         20U
#define APP_VALID_POINTS_MAX        (APP_FRAME_POINTS_MAX - APP_SKIP_FIRST_ROWS)
#define APP_DARK_ROWS               16U
#define APP_MEDIAN_WINDOW           9U
#define APP_SMOOTH_WINDOW           151U
#define APP_SMOOTH_ORDER            3U
#define APP_GROUP_COUNT_MAX         1U
#define APP_GROUP_REPLICATE_MAX     5U
#define APP_DOWNSAMPLE_STEP         16U
#define APP_DOWNSAMPLED_POINTS_MAX  ((APP_VALID_POINTS_MAX + APP_DOWNSAMPLE_STEP - 1U) / APP_DOWNSAMPLE_STEP)
#define APP_UART_RX_LINE_MAX        96U
#define APP_UART_TX_LINE_MAX        256U
#define APP_UART_IN_BAUDRATE        921600U
#define APP_UART_OUT_BAUDRATE       115200U
#define APP_NORM_Q15_SCALE          32767U

#define APP_INPUT_MODE_F103_BINARY  1U
#define APP_F103_REQUEST_12BIT_CMD  0xA1U
#define APP_F103_DEFAULT_GROUP_ID   1U
#define APP_F103_FIRST_PIXEL        0U
#define APP_F103_RX_TIMEOUT_MS      200U

#endif

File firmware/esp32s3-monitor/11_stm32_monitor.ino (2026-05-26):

#include <Arduino.h>
#include <lvgl.h>
#include <Arduino_GFX_Library.h>
#include <Preferences.h>
#include <Wire.h>
#include <WiFi.h>
#include <string>
#if defined(CONFIG_BLUEDROID_ENABLED)
#include <BLEDevice.h>
#endif
#include "bsp_cst816.h"

LV_FONT_DECLARE(ui_font_cn_16);

#define EXAMPLE_PIN_NUM_LCD_SCLK 39
#define EXAMPLE_PIN_NUM_LCD_MOSI 38
#define EXAMPLE_PIN_NUM_LCD_MISO 40
#define EXAMPLE_PIN_NUM_LCD_DC 42
#define EXAMPLE_PIN_NUM_LCD_RST -1
#define EXAMPLE_PIN_NUM_LCD_CS 45
#define EXAMPLE_PIN_NUM_LCD_BL 1
#define EXAMPLE_PIN_NUM_TP_SDA 48
#define EXAMPLE_PIN_NUM_TP_SCL 47

#define EXAMPLE_LCD_ROTATION 1
#define EXAMPLE_LCD_H_RES 240
#define EXAMPLE_LCD_V_RES 320

#define LEDC_FREQ 5000
#define LEDC_TIMER_10_BIT 10

#define STM32_LINK_BAUD 115200
// Default UART pins for the STM32 display link.
// Change these two macros if your ESP32-S3 board is wired to a different header.
#define STM32_LINK_RX_PIN 44
#define STM32_LINK_TX_PIN 43
#define STM32_DATA_RDY_PIN 18
#define STM32_WAKE_PIN 21

#define MONITOR_RX_LINE_MAX 256
#define MONITOR_CURVE_MAX 240
#define MONITOR_CHART_Y_MAX 1000
#define UI_FONT_CN (&ui_font_cn_16)
#define MONITOR_PREFS_NAMESPACE "g431mon"
#define LINK_STATUS_TOKEN_MAX 16
#define LINK_STATUS_AUTO_INTERVAL_MS 3000U
#define LINK_STATUS_TIMEOUT_MS 1200U
#define LINK_STATUS_STALE_MS 8000U

#define MONITOR_SERIAL_LOG_LINES 64
#define MONITOR_SERIAL_LINE_MAX 128

HardwareSerial Stm32Link(1);
Preferences g_preferences;

Arduino_DataBus *bus = new Arduino_ESP32SPI(
  EXAMPLE_PIN_NUM_LCD_DC,
  EXAMPLE_PIN_NUM_LCD_CS,
  EXAMPLE_PIN_NUM_LCD_SCLK,
  EXAMPLE_PIN_NUM_LCD_MOSI,
  EXAMPLE_PIN_NUM_LCD_MISO);

Arduino_GFX *gfx = new Arduino_ST7789(
  bus,
  EXAMPLE_PIN_NUM_LCD_RST,
  EXAMPLE_LCD_ROTATION,
  true,
  EXAMPLE_LCD_H_RES,
  EXAMPLE_LCD_V_RES);

typedef struct {
  bool valid;
  uint32_t seq;
  uint8_t groupId;
  uint8_t replicateId;
  uint16_t pointCount;
  uint16_t validCount;
  uint16_t firstPixel;
  uint16_t curveFirstPixel;
  uint16_t curveStep;
  uint16_t curveCount;
  float darkAdc;
  uint16_t peakRawPixel;
  uint16_t peakSmoothPixel;
  float intensityMean;
  float intensityMax;
  bool groupValid;
  uint8_t groupStatsId;
  uint8_t groupReplicateCount;
  uint16_t groupValidCount;
  uint16_t groupDownsampledCount;
  float meanPointCv;
  float corrMean;
  float corrMin;
  float peakMean;
  float peakStd;
  uint16_t curvePixels[MONITOR_CURVE_MAX];
  uint16_t curveQ15[MONITOR_CURVE_MAX];
  uint32_t receivedAtMs;
} MonitorPacket;

typedef struct {
  bool inPacket;
  bool curveOpen;
  uint16_t expectedCurveCount;
  uint16_t receivedCurveCount;
  char lastInfo[96];
  char lastError[96];
} ParserState;

typedef enum : uint8_t {
  LINK_QUERY_IDLE = 0,
  LINK_QUERY_WAITING = 1,
  LINK_QUERY_ONLINE = 2,
  LINK_QUERY_TIMEOUT = 3
} LinkQueryState;

typedef struct {
  LinkQueryState state;
  bool requestPending;
  bool autoEnabled;
  bool ready;
  bool wake;
  bool data;
  bool pending;
  uint32_t seq;
  uint32_t replicate;
  uint32_t valid;
  uint32_t sentAtMs;
  uint32_t repliedAtMs;
  uint32_t lastOkAtMs;
  uint32_t roundTripMs;
  uint32_t timeoutCount;
  uint32_t requestCounter;
  char pendingToken[LINK_STATUS_TOKEN_MAX];
  char lastToken[LINK_STATUS_TOKEN_MAX];
} LinkStatusState;

static MonitorPacket g_workPacket;
static MonitorPacket g_livePacket;
static ParserState g_parser;
static LinkStatusState g_linkStatus;

static char g_rxLine[MONITOR_RX_LINE_MAX];
static size_t g_rxLineLen = 0;
static bool g_livePacketDirty = false;
static uint32_t g_lastStatusRefreshMs = 0;
static uint32_t g_lastLinkStatusAutoMs = 0;

static uint32_t screenWidth = 0;
static uint32_t screenHeight = 0;
static uint32_t bufSize = 0;
static lv_color_t *dispDrawBuf = nullptr;
static lv_disp_draw_buf_t drawBuf;
static lv_disp_drv_t dispDrv;
static lv_indev_drv_t indevDrv;
static uint32_t g_lastLvglTickMs = 0;
static bool g_touchReady = false;
static uint32_t g_lastTouchRetryMs = 0;
static bool g_linkStreaming = true;
static bool g_preferencesReady = false;

static char g_wifiSsid[33] = "waveshare";
static char g_wifiPassword[65] = "12345678";
static char g_bleName[32] = "G431-Monitor";
static bool g_wifiAutoConnect = false;
static bool g_bleAutoStart = false;
#if defined(CONFIG_BLUEDROID_ENABLED)
static bool g_bleAdvertisingActive = false;
#endif

enum UiPage : uint8_t {
  UI_PAGE_ACQUIRE = 0,
  UI_PAGE_CURVE = 1,
  UI_PAGE_LINK = 2,
  UI_PAGE_SERIAL = 3,
  UI_PAGE_COUNT
};

static UiPage g_currentPage = UI_PAGE_ACQUIRE;

static lv_obj_t *labelTitle = nullptr;
static lv_obj_t *labelLink = nullptr;
static lv_obj_t *labelAcquireState = nullptr;
static lv_obj_t *labelAcquireG431 = nullptr;
static lv_obj_t *labelAcquireFrame = nullptr;
static lv_obj_t *labelAcquireStats = nullptr;
static lv_obj_t *labelAcquireGroup = nullptr;
static lv_obj_t *labelAcquireInfo = nullptr;
static lv_obj_t *labelCurve = nullptr;
static lv_obj_t *labelWifiStatus = nullptr;
static lv_obj_t *labelBleStatus = nullptr;
static lv_obj_t *chartCurve = nullptr;
static lv_chart_series_t *chartSeries = nullptr;
static lv_coord_t chartPoints[MONITOR_CURVE_MAX];
static lv_obj_t *navButtons[UI_PAGE_COUNT] = { nullptr };
static lv_obj_t *pageContainers[UI_PAGE_COUNT] = { nullptr };
static lv_obj_t *taWifiSsid = nullptr;
static lv_obj_t *taWifiPassword = nullptr;
static lv_obj_t *taBleName = nullptr;
static lv_obj_t *kbInput = nullptr;

static char g_serialLog[MONITOR_SERIAL_LOG_LINES][MONITOR_SERIAL_LINE_MAX];
static uint8_t g_serialLogHead = 0;
static uint8_t g_serialLogCount = 0;
static lv_obj_t *labelSerialLog = nullptr;
static bool g_serialLogDirty = false;

static void updatePageTitle() {
  if (labelTitle == nullptr) {
    return;
  }

  switch (g_currentPage) {
    case UI_PAGE_ACQUIRE:
      lv_label_set_text(labelTitle, "采集控制");
      break;
    case UI_PAGE_CURVE:
      lv_label_set_text(labelTitle, "曲线显示");
      break;
    case UI_PAGE_LINK:
      lv_label_set_text(labelTitle, "连接设置");
      break;
    case UI_PAGE_SERIAL:
      lv_label_set_text(labelTitle, "串口信息");
      break;
    default:
      lv_label_set_text(labelTitle, "STM32 G431");
      break;
  }
}

static void monitorClearPacket(MonitorPacket *packet) {
  if (packet == nullptr) {
    return;
  }
  memset(packet, 0, sizeof(*packet));
}

static void parserSetText(char *dst, size_t dstSize, const char *src) {
  if ((dst == nullptr) || (dstSize == 0U)) {
    return;
  }
  if (src == nullptr) {
    dst[0] = '\0';
    return;
  }
  strncpy(dst, src, dstSize - 1U);
  dst[dstSize - 1U] = '\0';
}

static bool beginPreferences() {
  if (g_preferencesReady) {
    return true;
  }

  g_preferencesReady = g_preferences.begin(MONITOR_PREFS_NAMESPACE, false);
  if (!g_preferencesReady) {
    Serial.println("Preferences begin failed");
  }
  return g_preferencesReady;
}
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

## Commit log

2026-05-26 Initial open-source release
    [1-1TCD1304采集数据_skip20_smoothed.csv, 1-1_cleaned.csv, 1-2_cleaned.csv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]
2026-05-26 Fix UART link flow and vendor ESP32 touch driver
    [app_main.c]
2026-05-26 Clarify V3 report claims and align PCB archive names
